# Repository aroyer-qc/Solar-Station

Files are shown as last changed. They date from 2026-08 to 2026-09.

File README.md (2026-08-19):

# SolarStation

ESP32-based solar station firmware for two-axis panel positioning, output scheduling, diagnostics, and network control. The firmware is designed for the Solar Station control PCB; its third stepper channel is currently unused by this project.

## Current Status

The firmware is in an active integration phase.

Implemented and working in firmware:

- FastAccelStepper integration with the PCB's 3 available stepper channels.
- Axis control on real steppers:
	- Azimuth controller uses Stepper1.
	- Elevation controller uses Stepper2.
	- Stepper3 is currently unused and available for future or other control applications.
- Configurable axis parameters (persisted):
	- Min/max angle limits.
	- Steps-per-degree ratio.
	- Step speed and acceleration.
- Portal dashboard + configuration UI (`/` and `/portal`) with sections for:
	- Solar tracking settings.
	- Axis settings.
	- Wi-Fi and NTP.
	- Output manual/auto control and schedules.
	- Hardware diagnostics (limit switches, driver DIAG, currents, sunrise/sunset).
- Output scheduler (3 outputs) with:
	- Fixed time or sunrise/sunset windows.
	- Duty cycle control.
	- AUTO/MANUAL mode per output.
- Wi-Fi behavior:
	- STA when configured.
	- AP fallback/setup mode when STA is not configured or fails.
- Sunset return preposition behavior:
	- Always active.
	- Executes once per target day.
	- Uses a fixed delay after local sunset before prepositioning to next sunrise target.
- Diagnostics override workflow:
	- Dedicated page (`/diag` and `/portal/diag`) to force azimuth/elevation for testing.
	- Canceling test mode returns panel to current calculated solar position.

## Testing Without Optional Hardware

The firmware includes compile-time switches for testing on an ESP32 without all of the connected hardware. In `Solar-Station.ino`, set any unavailable hardware feature to `0` before compiling:

```cpp
#define USE_BH1750_SENSOR 0  // Disable the BH1750 light sensor
#define USE_IO_EXPANDER   0  // Disable the PCA9538 I2C I/O expander
#define USE_M95P32        0  // Disable the M95P32 external SPI EEPROM
```

Available hardware switches:

- `USE_BH1750_SENSOR`: BH1750 light sensor support; default is `1`.
- `USE_IO_EXPANDER`: PCA9538 I2C I/O expander support; default is `1`.
- `USE_M95P32`: M95P32 external SPI EEPROM support; default is `1`.

Disable only the hardware that is not connected. With a feature disabled, its driver is excluded from the build and the related initialization and access code is skipped. The ESP32, firmware logic, web interface, and other enabled features can then be tested independently.

## Control PCB

The firmware is designed for the ESP32-based Solar Station control PCB shown below. The PCB can also be reused for other automation and control projects because it provides:

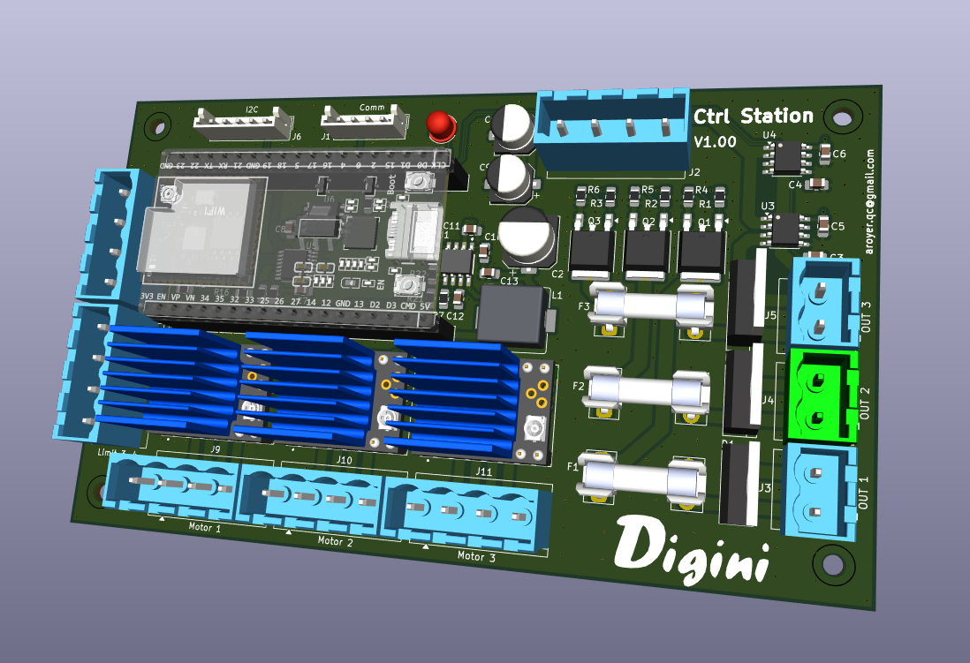
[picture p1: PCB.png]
Solar Station control PCB


- Three stepper motor controller channels; this project uses two for azimuth and elevation, while the third is currently unused.
- Inputs for switches such as limit switches and other digital status signals.
- Three MOSFET-controlled outputs that use the connected 12 V to 36 V power supply.
- One I2C port.
- One communication port.
- 3.3 V logic levels for the I2C and communication ports.

Check the electrical requirements of each connected motor, switch, and load before use. The MOSFET outputs switch the board's power-supply voltage, while the I2C and communication interfaces use 3.3 V logic.

## Hardware Notes (Current Wiring Assumptions)

- MCU: ESP32.
- Stepper drivers: TMC2209 (3 channels; two used by this project, one available).
- I/O expander: PCA9538 (I2C) for shared microstep pins, status LED, and limit switch inputs.
- External SPI EEPROM module support included (`M95PxxModule`).

## Main Runtime Modules

- `Solar-Station.ino`: orchestration, hardware init, scheduler, diagnostics helpers, sunset return, test override state.
- `ConfigModule.h` / `ConfigModule.ino`: persisted configuration storage and defaults.
- `AzimuthController.*`: azimuth axis control on FastAccelStepper.
- `ElevationController.*`: elevation axis control on FastAccelStepper.
- `WebServerModule.*`: synchronous web server routes and HTML placeholder binding.
- `WifiModule.*`: STA/AP behavior and reconnect strategy.
- `portal/index.html`: AP/setup portal page.
- `portal/diag.html`: diagnostics override page.
- `console/index.html`: full network console page.

Web UI deployment model:

- Local UI files are served from device filesystem (LittleFS/SPIFFS data partition).
- Use the `data` folder content and upload it with `tools/upload_spiffs.ps1` after firmware upload.
- Filesystem layout:
	- `data/portal/*` for AP/setup pages.
	- `data/console/*` for full network console pages.

## Web Endpoints (Current)

Main pages:

- `GET /` main dashboard/configuration page.
- `GET /portal` AP/setup portal page.
- `GET /diag` diagnostics test page.
- `GET /portal/diag` diagnostics test page.
- `GET /console` full network console page.
- `GET /diag/status` plain-text status snapshot for diagnostics page refresh.

Tracking diagnostics actions:

- `POST /setTrackingOverride` (form fields: `azimuth`, `elevation`).
- `POST /cancelTrackingOverride`.

Configuration actions (examples):

- `POST /saveSolarTrackingConfig`
- `POST /saveAzimuthConfig`
- `POST /saveElevationConfig`
- `POST /saveNTPConfig`
- `POST /saveWiFiConfig`
- `POST /saveScheduleConfig`

## Configuration Persistence

Configuration is stored with ESP32 Preferences.

- Main configuration uses a raw blob (`ConfigData_t`).
- Output AUTO/MANUAL flags are stored in separate keys (`out_auto_0..2`).

Important:

- Any structural change to `ConfigData_t` size causes existing blob data to be considered incompatible and defaults are restored on next boot.

## Build Portability (Another PC)

This project now includes the async network libraries in the project `libraries` folder, so the same code and patches follow the project:

- `libraries/ESPAsyncWebServer` (v3.1.0, with local compatibility patches)
- `libraries/AsyncTCP` (v1.1.4)
- `libraries/ESPAsyncTCP`

To build on another computer:

1. Install Arduino IDE 2.x.
2. Install `esp32` board platform in Boards Manager.
3. Open `Solar-Station.ino` from this project folder (do not copy only the `.ino` file).
4. Compile directly; do not install another conflicting `ESPAsyncWebServer` manually unless you intentionally want to replace the bundled one.

Recommended:

- If you already have other async web libraries globally installed in your Arduino libraries folder, keep versions aligned with this project to avoid API/link mismatches.

## Known Limitations / Work In Progress

- Legacy configuration compatibility paths and placeholder-based HTML binding remain in the codebase.
- Arduino IntelliSense can report false compile errors in editor context even when firmware logic is valid.
- Full production solar tracking loop policy (beyond targeted move and preposition behavior) may still need refinement for final deployment scenarios.

## Quick Validation Checklist

- Open `/` and verify dashboard values update.
- Confirm Wi-Fi mode (STA or AP fallback) is shown correctly.
- In configuration tabs, set axis limits/ratio/speed/acceleration and save.
- Use `/diag`:
	- Apply manual override.
	- Cancel test and verify return to current calculated position.
- Verify sunset return preposition occurs after sunset + fixed delay.

## License

This project is released under the [MIT License](https://opensource.org/license/mit/).

Project files contain their own headers where applicable.

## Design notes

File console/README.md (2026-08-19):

# SolarStation Console (ESP32-hosted)

This console UI is hosted directly by the ESP32 from filesystem storage.

Routes served by firmware:

- `/console`
- `/console/index.html`
- `/console/styles.css`
- `/console/app.js`

Deployment:

1. Keep source files in this folder for editing.
2. Copy or mirror files into `data/console`.
3. Upload SPIFFS with `tools/upload_spiffs.ps1`.

Notes:

- The console consumes the same device API endpoints as local pages.
- In AP mode, the default base URL is usually `http://192.168.4.1`.

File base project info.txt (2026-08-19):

https://www.youtube.com/watch?v=VaNVrE7-AO8

voir 9:30 pour savoir ou mettre arduino esp32fs-plugin
voir 21:00 pour savoir comment prendre une chart.js et la copier dans notre propre code

should see this : https://github.com/jblance/mpp-solar/tree/master
and this: https://github.com/cordelster/mppsolar_dashboards

https://github.com/HDwayne/SolarTracker

MC Series Register Map Overview
The MC Series (e.g., MC2420N10, MC2430N10, MC2440N10, MC2450N10) supports Modbus RTU communication via RS485.

 Here's a summary of key registers based on the official User manuals:
 Configuration Registers
 Register | Description              | Values / Range                         | 
 n01      | Battery Type             | 0: Sealed, 1: Gel, 2: Flooded, 3: User | 
 n02      | Equalization Voltage     | 12V: 14.8V, 24V: 29.6V                 | 
 n03      | Boost Voltage            | 12V: 14.4V, 24V: 28.8V                 | 
 n04      | Float Voltage            | 12V: 13.8V, 24V: 27.6V                 | 
 n05      | Boost Duration           | 10–120 min                             | 
 n06      | Equalization Duration    | 10–120 min                             | 
 n07      | Temperature Compensation | -3 to 0 mV/°C/cell                     | 
 n08      | System Voltage           | 0: Auto, 1: 12V, 2: 24V                | 
 n09      | Max Charging Current     | 10A–50A depending on model             | 

Monitoring Registers
 Register | Description            | 
 n30      | Battery Voltage        | 
 n31      | PV Input Voltage       | 
 n32      | Charging Current       | 
 n33      | Load Current           | 
 n34      | Controller Temperature | 
 n35      | Battery Temperature    | 
 n36      | Charging Power         | 
 n37      | Load Power             | 
These registers allow you to monitor real-time performance and adjust charging behavior.

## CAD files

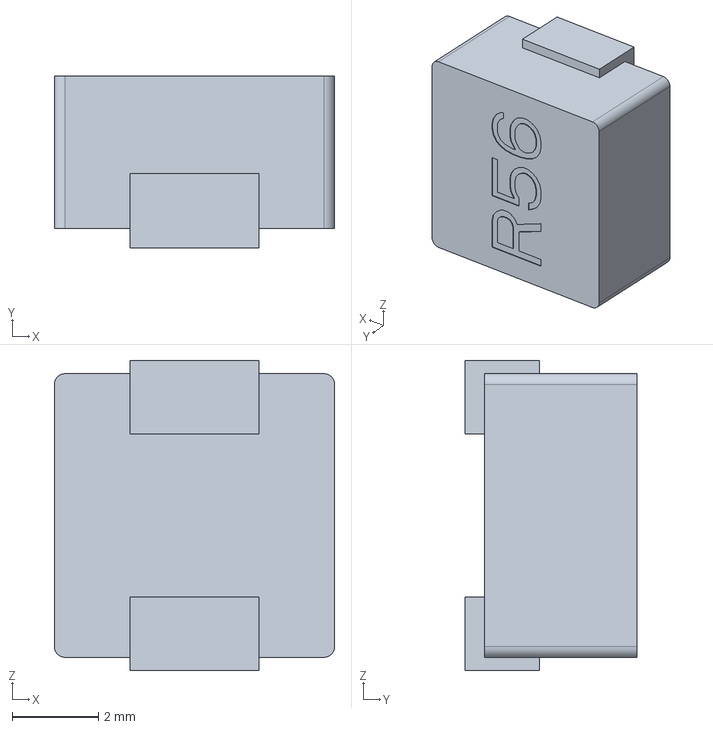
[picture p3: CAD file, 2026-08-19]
Ressource/ControlBox/srp6540-4r7m.stp
6.50 x 3.99 x 7.19 mm

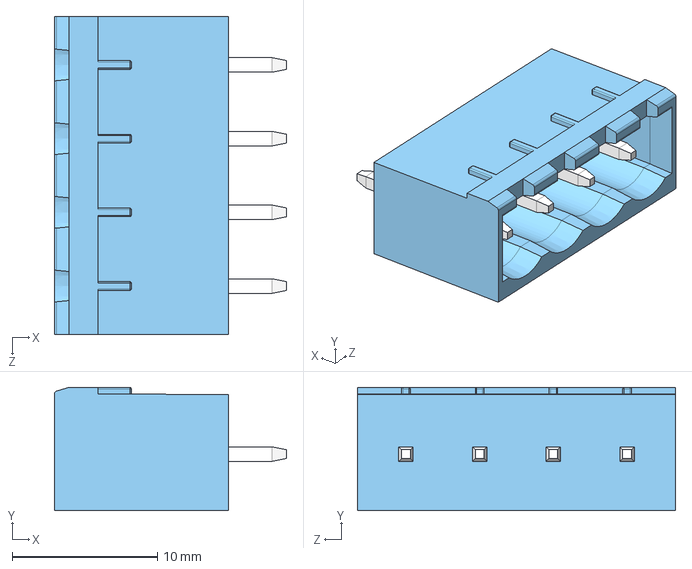
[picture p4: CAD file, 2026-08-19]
Ressource/ControlBox/TerminalBlock 4P.STEP
16.0 x 8.50 x 21.9 mm

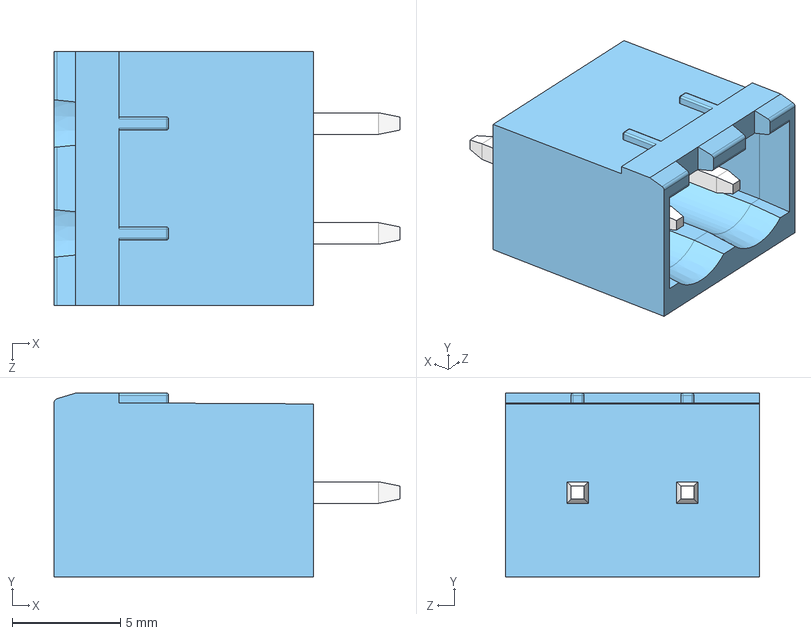
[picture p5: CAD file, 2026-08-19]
Ressource/ControlBox/TerminalBlock 2P.STEP
16.0 x 8.50 x 11.8 mm

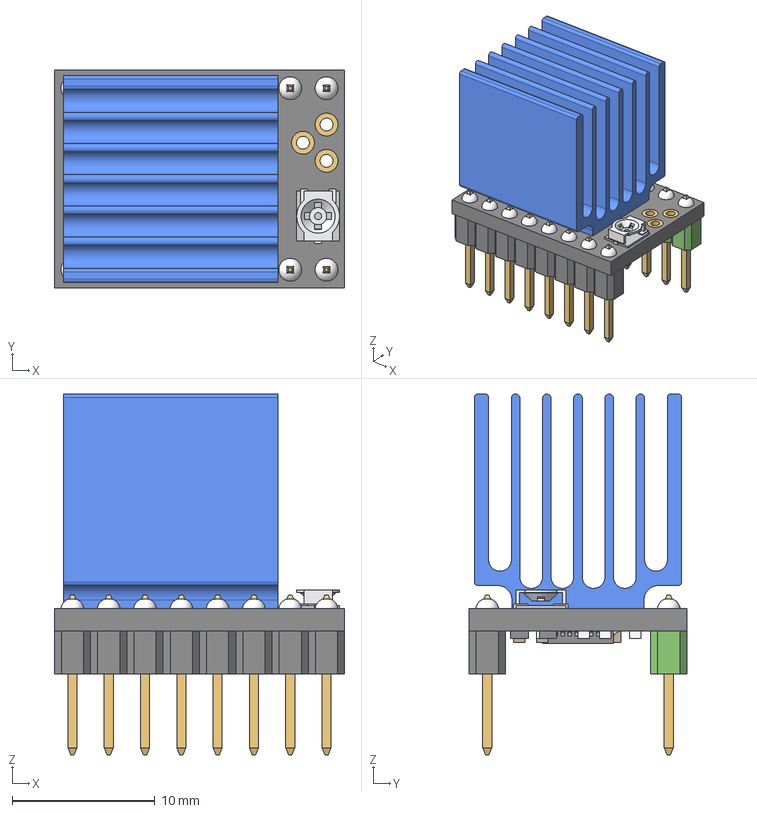
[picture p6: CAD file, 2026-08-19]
Ressource/ControlBox/TMC2209.step
20.3 x 15.2 x 25.3 mm
Body001 (Mirror #1)
Body001 (Mirror #1)001
Body001 (Mirror #1)002
Body001 (Mirror #1)003
Body001 (Mirror #1)004
Body001 (Mirror #1)005
Body001 (Mirror #1)006
Body001 (Mirror #1)007
Body001 (Mirror #1)008
Body001 (Mirror #1)009
Body001 (Mirror #1)010
Body001 (Mirror #1)011
Body001 (Mirror #1)012
Body001 (Mirror #1)013

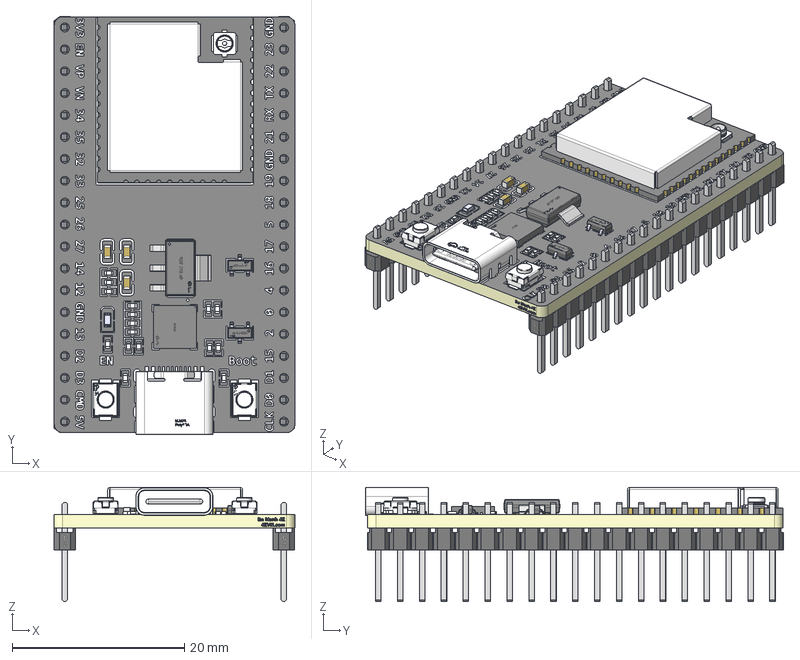
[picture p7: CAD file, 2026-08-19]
Ressource/ControlBox/ESP32-DEVKITC-32U.STEP
27.9 x 48.5 x 13.2 mm
Board~QTmk
TopSilkscreen~QTmk
BottomSilkscreen~QTmk
USB-C_SMD-TYPE-C-31-M-12~USB-C_SMD-TYPE-C-31-M-12~QTmk
C0603~C0603_L1.6-W0.8-H0.8~QTmk x 3
R0402~R0402_L1.0-W0.5-H0.4~QTmk x 16
SOT-223-3_L6.5-W3.4-P2.30-LS7.0-BR~SOT-223-4P_L6.5-W3.5-H1.6-LS7.0-P2. 30~QTmk
SW-SMD_L3.9-W3.0-P4.45~SW-SMD_L3.9-W2.9-H2.0-LS4.8~QTmk x 2
LED0603-RD_RED~LED0603-RD_RED~QTmk
HDR-TH_19P-P2.54-V-M~HDR-TH_19P-P2.54-M-LI-1X19P~QTmk x 2
SOT-23-3_L2.9-W1.3-P1.90-LS2.4-BR~SOT-23-3P_L2.9-W1.3-H1.0-LS2.4-P0.9 5~QTmk x 2
QFN-28_L5.0-W5.0-P0.50-TL-EP3.3~QFN-28_L5.0-W5.0-H0.9-P0.50~QTmk
ESP32_5x5_20210301.STEP^ESP32_5x5_20210301.STEP_Submodel-QFN48EB_0P35 _5_part_DesignRootModel_ESP32-WROOM-32UE(2)_ESP32-WROOM-32UE.STEP
DFN1006.STEP^DFN1006.STEP_Submodel-SOD882_part_DesignRootModel_ESP32- WROOM-32UE(2)_ESP32-WROOM-32UE.STEP
XTAL3225_20210301.STEP^XTAL3225_20210301.STEP_Submodel-XTAL3225_part_ DesignRootModel_ESP32-WROOM-32UE(2)_ESP32-WROOM-32UE.STEP
C0402_20210301.STEP^C0402_20210301.STEP_Submodel-C0402_part_DesignRoo tModel_ESP32-WROOM-32UE(2)_ESP32-WROOM-32UE.STEP
SOIC8_208_20210301.STEP^SOIC8_208_20210301.STEP_Submodel-SOP8_1P27_6P 6_part_DesignRootModel_ESP32-WROOM-32UE(2)_ESP32-WROOM-32UE.STEP
L0201_20210301.STEP^L0201_20210301.STEP_Submodel-L0201_part_DesignRoo tModel_ESP32-WROOM-32UE(2)_ESP32-WROOM-32UE.STEP x 2
R0201_20210301.STEP^R0201_20210301.STEP_Submodel-R0201_part_DesignRoo tModel_ESP32-WROOM-32UE(2)_ESP32-WROOM-32UE.STEP x 3
C0201_20210301.STEP^C0201_20210301.STEP_Submodel-C0201_part_DesignRoo tModel_ESP32-WROOM-32UE(2)_ESP32-WROOM-32UE.STEP x 15
uid__1081685072^DesignRootModel_ESP32-WROOM-32UE(2)_ESP32-WROOM-32UE. STEP
pad.STEP x 38
ESP32-WROOM-32U_Shieldingcase_20210312.STEP
32E_thermal_pad.STEP
I-IPEX

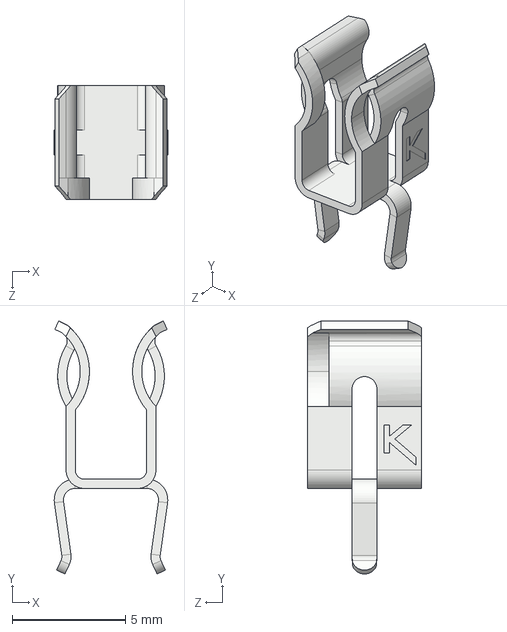
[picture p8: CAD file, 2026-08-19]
Ressource/ControlBox/FuseHolderClip.STEP
5.00 x 11.1 x 5.00 mm

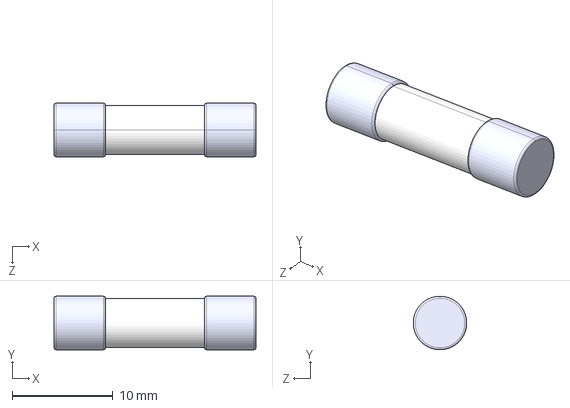
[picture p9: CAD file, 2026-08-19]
Ressource/ControlBox/fuse.STEP
20.0 x 5.30 x 5.30 mm

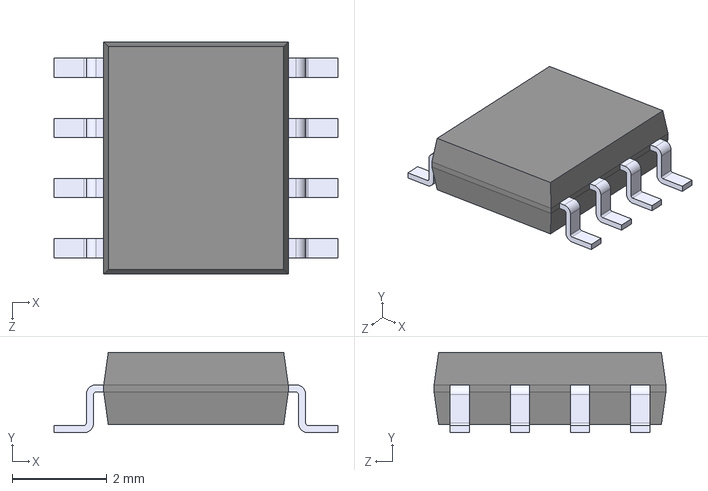
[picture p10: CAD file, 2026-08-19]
Ressource/ControlBox/AP64100SP-13.STEP
6.00 x 1.70 x 4.90 mm

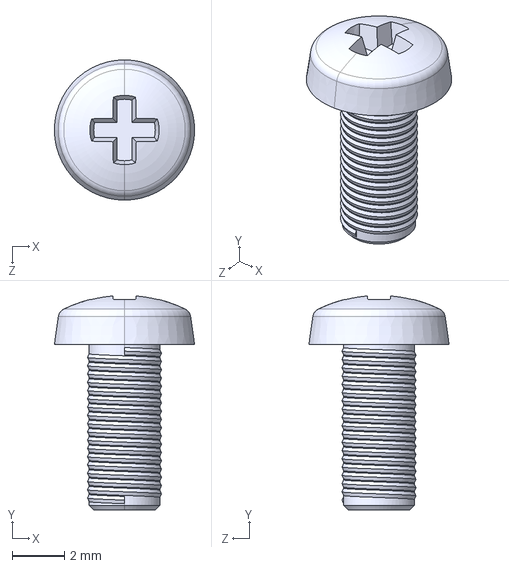
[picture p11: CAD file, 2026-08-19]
Ressource/ControlBox/screw M2x20.STEP
5.38 x 8.21 x 5.38 mm

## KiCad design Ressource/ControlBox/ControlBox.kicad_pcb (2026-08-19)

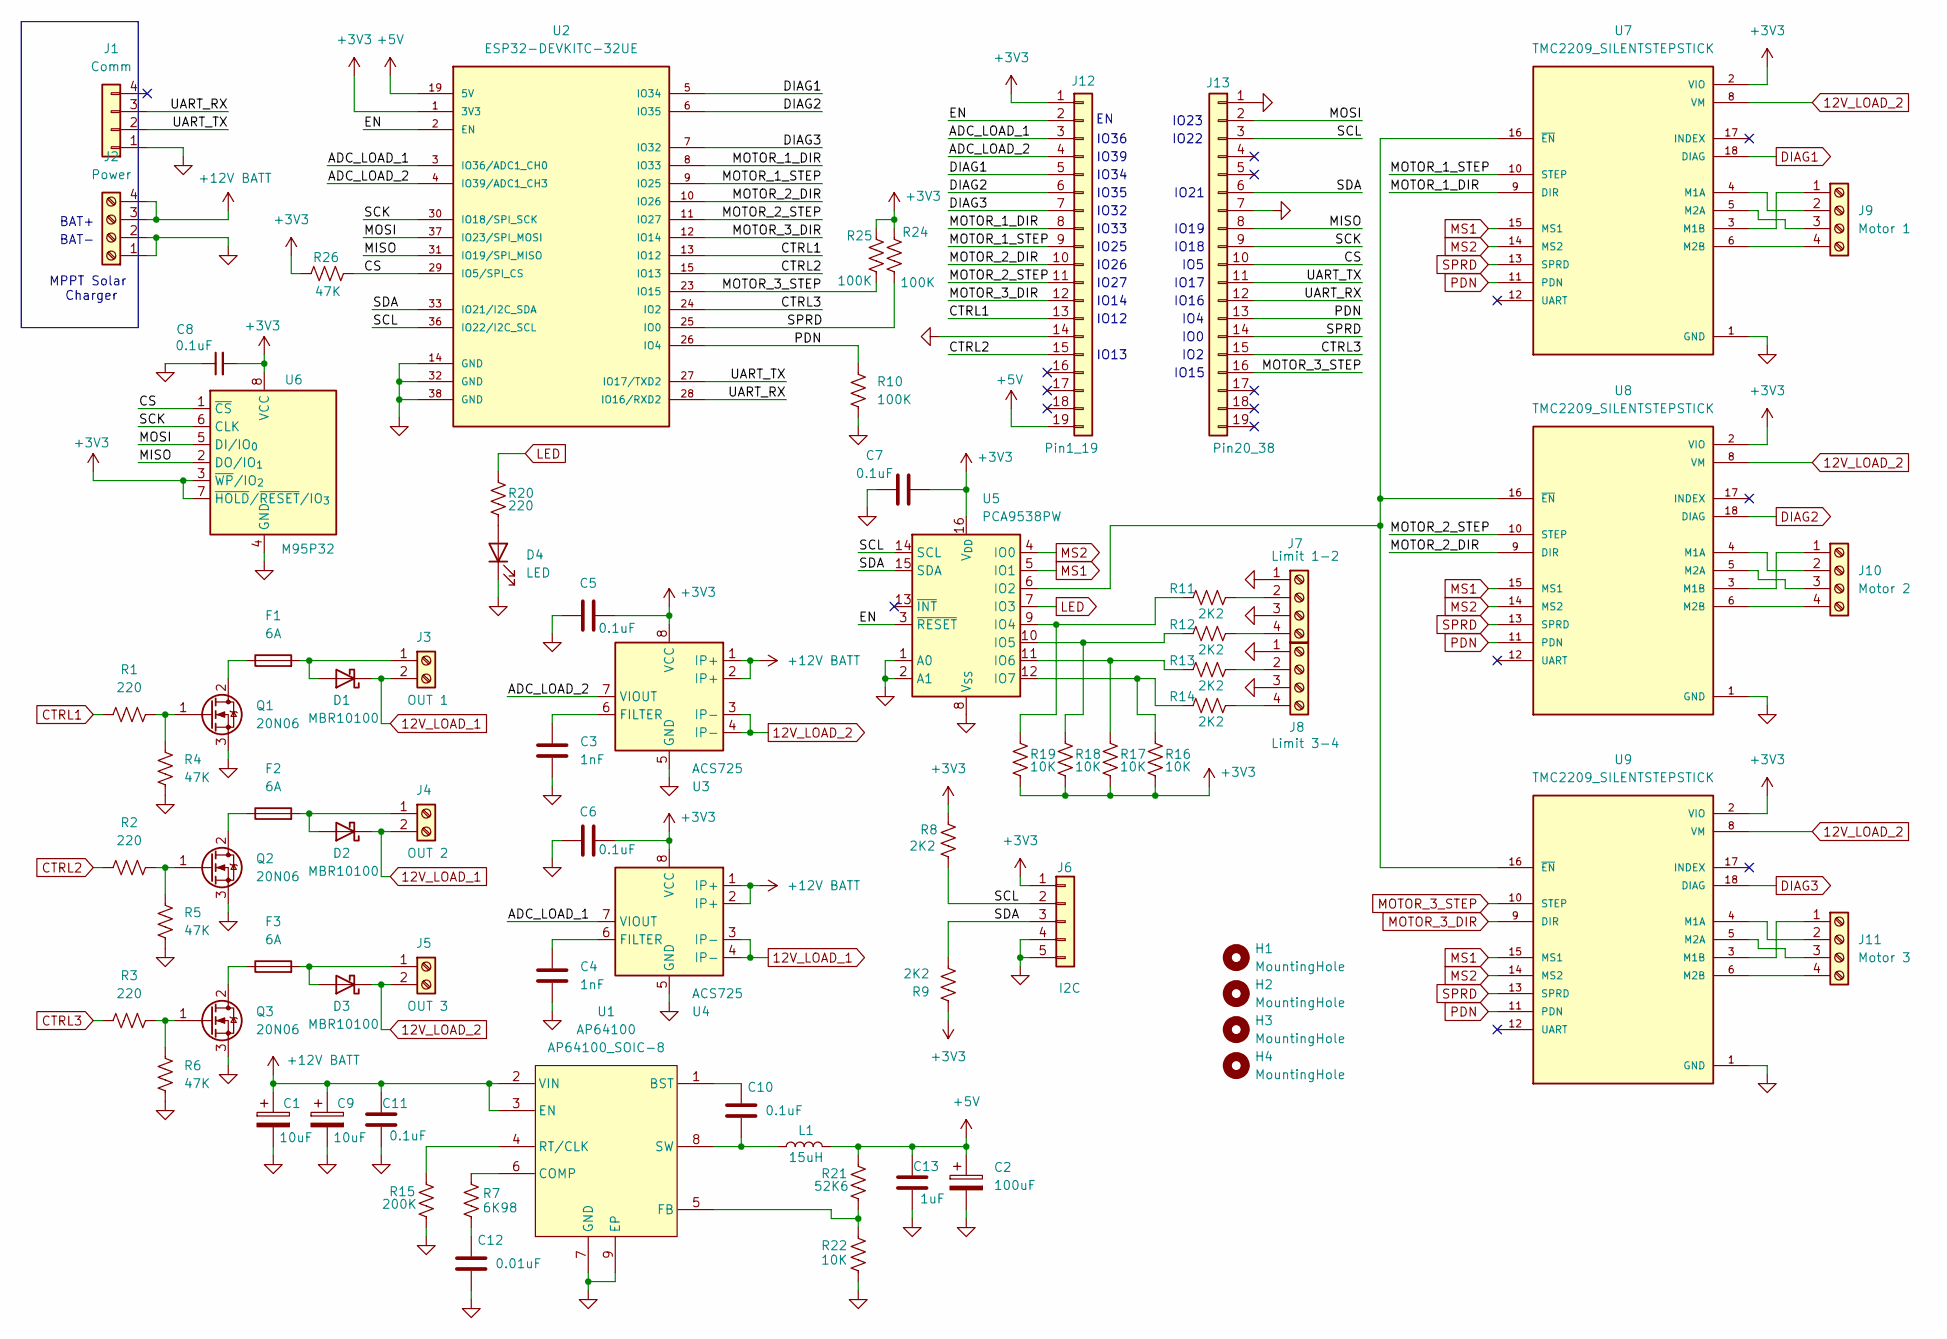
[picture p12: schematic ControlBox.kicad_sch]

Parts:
C1, C9: 10uF; CP_Elec_6.3x5.4
C2: 100uF; CP_Elec_8x6.7
C3, C4: 1nF; C_0805_2012Metric_Pad1.18x1.45mm_HandSolder
C5, C6, C7, C8, C10, C11: 0.1uF; C_0805_2012Metric_Pad1.18x1.45mm_HandSolder
C12: 0.01uF; C_0805_2012Metric_Pad1.18x1.45mm_HandSolder
C13: 1uF; C_0805_2012Metric_Pad1.18x1.45mm_HandSolder
D1, D2, D3: MBR10100; TO-220-2_Vertical
D4: LED; LED_D4.0mm
F1, F2, F3: 6A; Fuseholder_Clip-4x15mm_Generic_Horizontal
H1, H2, H3, H4: MountingHole; MountingHole_2.7mm_M2.5
J1: Comm; JST_EH_B4B-EH-A_1x04_P2.50mm_Vertical
J2: Power; TerminalBlock_CUI_TB007-508-04_1x04_P5.08mm_Horizontal
J3: OUT 1; TerminalBlock_CUI_TB007-508-02_1x02_P5.08mm_Horizontal
J4: OUT 2; TerminalBlock_CUI_TB007-508-02_1x02_P5.08mm_Horizontal
J5: OUT 3; TerminalBlock_CUI_TB007-508-02_1x02_P5.08mm_Horizontal
J6: I2C; JST_EH_B5B-EH-A_1x05_P2.50mm_Vertical
J7: Limit 1-2; TerminalBlock_CUI_TB007-508-04_1x04_P5.08mm_Horizontal
J8: Limit 3-4; TerminalBlock_CUI_TB007-508-04_1x04_P5.08mm_Horizontal
J9: Motor 1; TerminalBlock_CUI_TB007-508-04_1x04_P5.08mm_Horizontal
J10: Motor 2; TerminalBlock_CUI_TB007-508-04_1x04_P5.08mm_Horizontal
J11: Motor 3; TerminalBlock_CUI_TB007-508-04_1x04_P5.08mm_Horizontal
J12: Pin1_19; PinHeader_1x19_P2.54mm_Vertical
J13: Pin20_38; PinHeader_1x19_P2.54mm_Vertical
L1: 15uH; L_Bourns_SRP1038C_10.0x10.0mm
Q1, Q2, Q3: 20N06; TO-252-2
R1, R2, R3, R20: 220; R_0805_2012Metric_Pad1.20x1.40mm_HandSolder
R4, R5, R6, R26: 47K; R_0805_2012Metric_Pad1.20x1.40mm_HandSolder
R7: 6K98; R_0805_2012Metric_Pad1.20x1.40mm_HandSolder
R8, R9, R11, R12, R13, R14: 2K2; R_0805_2012Metric_Pad1.20x1.40mm_HandSolder
R10, R24, R25: 100K; R_0805_2012Metric_Pad1.20x1.40mm_HandSolder
R15: 200K; R_0805_2012Metric_Pad1.20x1.40mm_HandSolder
R16, R17, R18, R19, R22: 10K; R_0805_2012Metric_Pad1.20x1.40mm_HandSolder
R21: 52K6; R_0805_2012Metric_Pad1.20x1.40mm_HandSolder
U1: AP64100; AP64100_SOIC-8
U2: ESP32-DEVKITC-32UE; PARTREV V4
U3, U4: ACS725; SOIC-8_3.9x4.9mm_P1.27mm
U5: PCA9538PW; TSSOP-16_4.4x5mm_P0.65mm
U6: M95P32; SOIC-8_5.3x5.3mm_P1.27mm
U7, U8, U9: TMC2209_SILENTSTEPSTICK; MOD_TMC2209; PARTREV 1.20

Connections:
12V_LOAD_1: D1.1 (K), D2.1 (K), J3.2, J4.2, U4.3 (IP-), U4.4 (IP-)
12V_LOAD_2: D3.1 (K), J5.2, U3.3 (IP-), U3.4 (IP-), U7.8 (VM), U8.8 (VM), U9.8 (VM)
+3V3: C5.2, C6.2, C7.2, C8.2, J6.1, J12.1, R8.1, R9.1, R16.2, R17.2, R18.2, R19.2, R24.1, R25.1, R26.1, U2.1 (3V3), U3.8 (VCC), U4.8 (VCC), U5.16 (V_{DD}), U6.3 (~WP/IO_{2}), U6.7 (~HOLD/~RESET/IO_{3}), U6.8 (VCC), U7.2 (VIO), U8.2 (VIO), U9.2 (VIO)
+5V: C2.1, C13.1, J12.19, L1.2, R21.1, U2.19 (5V)
+12V BATT: C1.1, C9.1, C11.1, J2.3, J2.4, U1.2 (VIN), U1.3 (EN), U3.1 (IP+), U3.2 (IP+), U4.1 (IP+), U4.2 (IP+)
/ADC_LOAD_1: J12.3, U2.3 (IO36/ADC1_CH0), U4.7 (VIOUT)
/ADC_LOAD_2: J12.4, U2.4 (IO39/ADC1_CH3), U3.7 (VIOUT)
/CS: J13.10, R26.2, U2.29 (IO5/SPI_CS), U6.1 (~CS)
/EN: J12.2, U2.2 (EN), U5.3 (~RESET)
/MISO: J13.8, U2.31 (IO19/SPI_MISO), U6.2 (DO/IO_{1})
/MOSI: J13.2, U2.37 (IO23/SPI_MOSI), U6.5 (DI/IO_{0})
/MOTOR_1_DIR: J12.8, U2.8 (IO33), U7.9 (DIR)
/MOTOR_1_STEP: J12.9, U2.9 (IO25), U7.10 (STEP)
/MOTOR_2_DIR: J12.10, U2.10 (IO26), U8.9 (DIR)
/MOTOR_2_STEP: J12.11, U2.11 (IO27), U8.10 (STEP)
/SCK: J13.9, U2.30 (IO18/SPI_SCK), U6.6 (CLK)
/SCL: J6.2, J13.3, R8.2, U2.36 (IO22/I2C_SCL), U5.14 (SCL)
/SDA: J6.3, J13.6, R9.2, U2.33 (IO21/I2C_SDA), U5.15 (SDA)
/UART_RX: J1.3, J13.12, U2.28 (IO16/RXD2)
/UART_TX: J1.2, J13.11, U2.27 (IO17/TXD2)
CTRL1: J12.13, R1.1, U2.13 (IO12)
CTRL2: J12.15, R2.1, U2.15 (IO13)
CTRL3: J13.15, R3.1, U2.24 (IO2)
DIAG1: J12.5, U2.5 (IO34), U7.18 (DIAG)
DIAG2: J12.6, U2.6 (IO35), U8.18 (DIAG)
DIAG3: J12.7, U2.7 (IO32), U9.18 (DIAG)
GND: C1.2, C2.2, C3.2, C4.2, C5.1, C6.1, C7.1, C8.1, C9.2, C11.2, C12.2, C13.2, D4.1 (K), J1.1, J2.1, J2.2, J6.4, J6.5, J7.1, J7.3, J8.1, J8.3, J12.14, J13.1, J13.7, Q1.3 (S), Q2.3 (S), Q3.3 (S), R4.2, R5.2, R6.2, R10.2, R15.2, R22.2, U1.7 (GND), U1.9 (EP), U2.14 (GND), U2.32 (GND), U2.38 (GND), U3.5 (GND), U4.5 (GND), U5.1 (A0), U5.2 (A1), U5.8 (V_{SS}), U6.4 (GND), U7.1 (GND), U7.7 (GND), U8.1 (GND), U8.7 (GND), U9.1 (GND), U9.7 (GND)
LED: R20.1, U5.7 (IO3)
MOTOR_3_DIR: J12.12, U2.12 (IO14), U9.9 (DIR)
MOTOR_3_STEP: J13.16, R25.2, U2.23 (IO15), U9.10 (STEP)
MS1: U5.5 (IO1), U7.15 (MS1), U8.15 (MS1), U9.15 (MS1)
MS2: U5.4 (IO0), U7.14 (MS2), U8.14 (MS2), U9.14 (MS2)
unnamed: C12.1, R7.2
unnamed: D1.2 (A), F1.2, J3.1
unnamed: D2.2 (A), F2.2, J4.1
unnamed: D3.2 (A), F3.2, J5.1
unnamed: D4.2 (A), R20.2
unnamed: J7.2, R11.2
unnamed: J7.4, R12.2
unnamed: J8.2, R13.2
unnamed: J8.4, R14.2
unnamed: J9.1, U7.3 (M1B)
unnamed: J9.2, U7.4 (M1A)
unnamed: J9.3, U7.5 (M2A)
unnamed: J9.4, U7.6 (M2B)
unnamed: J10.1, U8.3 (M1B)
unnamed: J10.2, U8.4 (M1A)
unnamed: J10.3, U8.5 (M2A)
unnamed: J10.4, U8.6 (M2B)
unnamed: J11.1, U9.3 (M1B)
unnamed: J11.2, U9.4 (M1A)
unnamed: J11.3, U9.5 (M2A)
unnamed: J11.4, U9.6 (M2B)
unnamed: F1.1, Q1.2 (D)
unnamed: Q1.1 (G), R1.2, R4.1
unnamed: F2.1, Q2.2 (D)
unnamed: Q2.1 (G), R2.2, R5.1
unnamed: F3.1, Q3.2 (D)
unnamed: Q3.1 (G), R3.2, R6.1
unnamed: C10.1, U1.1 (BST)
unnamed: R7.1, U1.6 (COMP)
unnamed: R21.2, R22.1, U1.5 (FB)
unnamed: R15.1, U1.4 (RT/CLK)
unnamed: C10.2, L1.1, U1.8 (SW)
unnamed: C3.1, U3.6 (FILTER)
unnamed: C4.1, U4.6 (FILTER)
unnamed: U5.6 (IO2), U7.16 (~EN), U8.16 (~EN), U9.16 (~EN)
unnamed: R11.1, R19.1, U5.9 (IO4)
unnamed: R12.1, R18.1, U5.10 (IO5)
unnamed: R13.1, R17.1, U5.11 (IO6)
unnamed: R14.1, R16.1, U5.12 (IO7)
PDN: J13.13, R10.1, U2.26 (IO4), U7.11 (PDN), U8.11 (PDN), U9.11 (PDN)
SPRD: J13.14, R24.2, U2.25 (IO0), U7.13 (SPRD), U8.13 (SPRD), U9.13 (SPRD)

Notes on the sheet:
IO32
IO27
IO17
MPPT Solar Charger
IO13
BAT-
IO36
IO21
IO18
IO14
IO25
IO26
IO0
IO34
IO19
IO35
IO15
IO2
IO4
IO16
IO33
IO22
IO5
IO12
IO23
IO39
BAT+

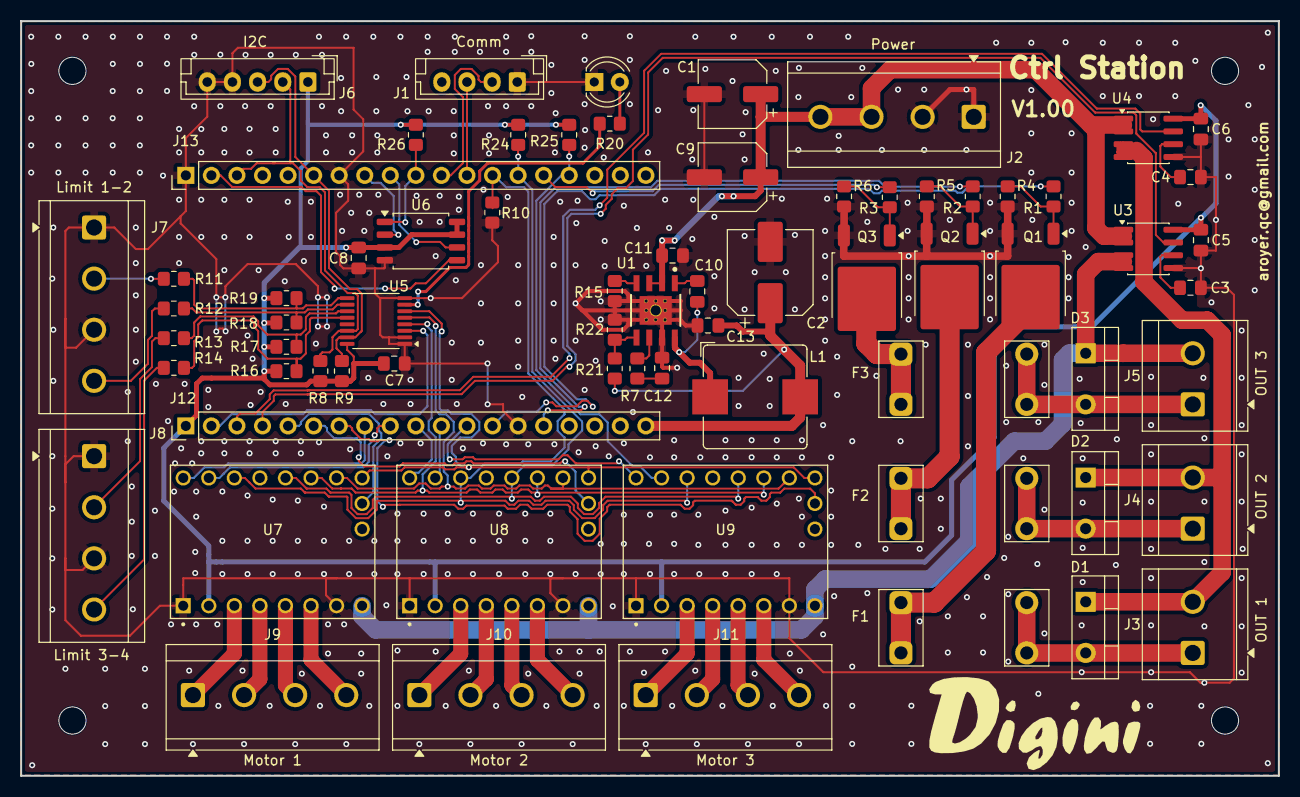
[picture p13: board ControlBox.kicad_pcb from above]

Board: 2 copper layers, 125.0 x 75.0 mm, 74 parts (0 on the bottom side), 73 nets.

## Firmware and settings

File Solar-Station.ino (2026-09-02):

//-------------------------------------------------------------------------------------------------
//
//  File : Solar-Station.ino
//
//-------------------------------------------------------------------------------------------------
//
// Copyright(c) 2025 Alain Royer.
// Email: aroyer.qc@gmail.com
//
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
//-------------------------------------------------------------------------------------------------
//
//    Solar Station
//
//        - Tracking panel.
//            * control motor.
//        
//        - Monitor panel voltage and current.
//        - Monitor battery voltage and current flow in or out.
//        - monitor load current.
//        - Control IO according to schedule and or power availability
//        - more to add...
//
//
// Filesystem upload procedure (required to serve local web pages from /data):
// 1) Build and upload firmware from Arduino IDE as usual.
// 2) Open PowerShell in the project root folder.
// 3) Run the helper script with your serial port and partition scheme.
//
// Example commands:
//   .\tools\upload_spiffs.ps1 -Port COMx -Partition default
//   .\tools\upload_spiffs.ps1 -Port COMx -Partition no_ota
//   .\tools\upload_spiffs.ps1 -Port COMx -Partition huge_app
//   .\tools\upload_spiffs.ps1 -Port COMx -Partition min_spiffs
//
// Notes:
// - Use the same partition scheme selected in Arduino IDE (Tools > Partition Scheme).
// - The script packs files from /data into a SPIFFS image and writes it to flash.
// - If pages are blank, upload firmware then rerun this script and reboot the ESP32.
//
//
//-------------------------------------------------------------------------------------------------

//-------------------------------------------------------------------------------------------------
// Include file(s)
//-------------------------------------------------------------------------------------------------

#include <Wire.h>

// #define USE_DEBUG_APP

#ifndef USE_BH1750_SENSOR
#define USE_BH1750_SENSOR            1
#endif

#ifndef USE_IO_EXPANDER
#define USE_IO_EXPANDER              1
#endif

#ifndef USE_M95P32
#define USE_M95P32                   1
#endif

#if USE_BH1750_SENSOR
#include <BH1750.h>
#endif
#include "SolarFixed.h"
#include <math.h>
#include "ConfigModule.h"
#include "WiFiModule.h"
#include "WebServerModule.h"
#include "TelemetryModule.h"
#include "SchedulerModule.h"
#include "TrackingModule.h"
#include "FastAccelStepper.h"
#include "AzimuthController.h"
#include "ElevationController.h"
#include "SensorLoggerModule.h"
#include <sys/time.h>

#if USE_M95P32
#include "M95PxxModule.h"
#endif

//-------------------------------------------------------------------------------------------------
// Define(s)
//-------------------------------------------------------------------------------------------------

// Miscellaneous Default

#define DEFAULT_SERIAL_BAUD_RATE        115200

//-------------------------------------------------------------------------------------------------
// Default positions

//-------------------------------------------------------------------------------------------------
// IO definitions

// UART2 (configure pins as needed)
// ESP32 module pins: 27 -> GPIO16, 28 -> GPIO17
#define UART2_TX_PIN                    17
#define UART2_RX_PIN                    16
#define UART2_BAUDRATE                  9600
#define MPPT_MODBUS_ADDRESS             0xFF
#define MPPT_MODBUS_FUNC_READ_HOLDING   0x03

// Read Battery SOC (Value * 1 - Ex: 0x00 0x37 = 55%)
// CMD:	0x100  Bytes Read 2
// Read Battery voltage (Value * 0.1 - Ex: 0x00 0x7A = 12.2V)
// CMD:	0x101  Bytes Read 2
// Read Charging Current to Battery (Value * 0.01 - Ex: 0x01 0x0A = 2.66A)
// CMD:	0x102  Bytes Read 2
// Read Panel voltage (Value * 0.1 - Ex: 0x00 0xC8 = 20.0V)
// CMD:	0x107  Bytes Read 2
// Read Panel current to controller (Value * 0.01 - Ex: 0x01 0x0A = 2.66A)
// CMD:	0x108  Bytes Read 2
// Read Panel Charging power (Value * 1 - Ex: 0x00 0x35 = 55W)
// CMD:	0x109  Bytes Read 2
#define MPPT_REG_BATTERY_SOC            0x0100
#define MPPT_REG_BATTERY_VOLTAGE        0x0101
#define MPPT_REG_CHARGE_CURRENT         0x0102
#define MPPT_REG_PANEL_VOLTAGE          0x0107
#define MPPT_REG_PANEL_CURRENT          0x0108
#define MPPT_REG_PANEL_CHARGING_POWER   0x0109
// UART2 Serial port

// PCA9538PW (MS1/MS2 via IO expander on I2C)
#define PCA9538_I2C_ADDRESS             0x70
#define PCA9538_REG_INPUT               0x00
#define PCA9538_REG_OUTPUT              0x01
#define PCA9538_REG_POLARITY            0x02
#define PCA9538_REG_CONFIG              0x03

// 3x TMC2209 stepper wiring
#define STEPPER1_DIR_PIN                33
#define STEPPER1_STEP_PIN               25
#define STEPPER2_DIR_PIN                26
#define STEPPER2_STEP_PIN               27
#define STEPPER3_DIR_PIN                14
#define STEPPER3_STEP_PIN               15

// Driver diagnostic inputs
#define STEPPER1_DIAG_PIN               34
#define STEPPER2_DIAG_PIN               35
#define STEPPER3_DIAG_PIN               32

// Adjust to LOW if your driver DIAG is active-low
#define STEPPER_DIAG_ACTIVE_STATE       HIGH

// Shared control lines for all 3 drivers
#define STEPPER_PDN_SHARED_PIN           4
#define STEPPER_SPRD_SHARED_PIN          0

// Defaults can be updated later from config/IO expander logic
#define STEPPER_PDN_DEFAULT_STATE        HIGH
#define STEPPER_SPRD_DEFAULT_STATE       LOW

// PCA9538 pin mapping for microstep control (shared in parallel for all 3 steppers)
// MS2 -> IO0, MS1 -> IO1
#define STEPPER_MS2_EXP_PIN              0
#define STEPPER_MS1_EXP_PIN              1
#define STEPPER_EN_EXP_PIN               2

// Shared TMC2209 EN line through PCA9538 IO2.
// Most TMC2209 modules use EN active-low.
#define STEPPER_EN_ACTIVE_STATE          LOW
#define STEPPER_EN_INACTIVE_STATE        HIGH

// PCA9538 status LED output
#define STATUS_LED_EXP_PIN               3
#define STATUS_LED_ON_STATE              LOW
#define STATUS_LED_OFF_STATE             HIGH
#define STATUS_LED_BLINK_INTERVAL_MS     500

// PCA9538 limit switches (wired to GND)
#define LIMIT_SWITCH1_EXP_PIN            4
#define LIMIT_SWITCH2_EXP_PIN            5
#define LIMIT_SWITCH3_EXP_PIN            6
#define LIMIT_SWITCH4_EXP_PIN            7
#define LIMIT_SWITCH_ACTIVE_STATE        LOW

// Default microstep profile on MS pins (can be changed from config later)
#define STEPPER_MS1_DEFAULT_STATE        LOW
#define STEPPER_MS2_DEFAULT_STATE        LOW

// ADC on ADC1
// ACS725 sensors:
// - Load 1 current on ADC1_CH0 (GPIO36)
// - Load 2 current on ADC1_CH3 (GPIO39)
#define ACS725_SENS_CUR_LOAD1_PIN        36
#define ACS725_SENS_CUR_LOAD2_PIN        39

// 3x MOSFET low-side outputs
#define MOSFET_OUTPUT1_PIN               12
#define MOSFET_OUTPUT2_PIN               13
#define MOSFET_OUTPUT3_PIN               2

// ESP32 LEDC PWM configuration for MOSFET outputs
#define MOSFET_PWM_FREQ_HZ               20000
#define MOSFET_PWM_RES_BITS              10

//-------------------------------------------------------------------------------------------------

// Per-sensor calibration:
// - SIGN: use +1.0f for normal polarity, -1.0f to invert current direction
// - OFFSET_A: residual current offset in amps when true current is 0 A

#define ADC_REF_VOLTAGE                  (float(3.3))                // ESP32 ADC reference/supply voltage
#define ESP32_ADC_RESOLUTION             4095                        // 12-bit ADC
#define ACS725_SAMPLES_PER_READ          8u
#define ACS725_LOAD1_SENSITIVITY_V_PER_A (float(0.132))              // ACS725 0-20A unidirectional sensitivity at 3.3V (about 132mV/A)
#define ACS725_LOAD2_SENSITIVITY_V_PER_A (float(0.132))              // ACS725 0-20A unidirectional sensitivity at 3.3V (about 132mV/A)
#define ACS725_LOAD1_ZERO_CURRENT_VOLTAGE (float(0.33))              // Unidirectional quiescent output near 10% of Vcc (adjust by calibration)
#define ACS725_LOAD2_ZERO_CURRENT_VOLTAGE (float(0.33))              // Unidirectional quiescent output near 10% of Vcc (adjust by calibration)

// Per-sensor calibration:
// - SIGN: use +1.0f for normal polarity, -1.0f to invert current direction
// - OFFSET_A: residual current offset in amps when true current is 0 A
#define ACS725_LOAD1_SIGN                (1.0f)
#define ACS725_LOAD2_SIGN                (1.0f)
#define ACS725_LOAD1_OFFSET_A            (0.0f)
#define ACS725_LOAD2_OFFSET_A            (0.0f)
#define ACS725_CLAMP_NEGATIVE_TO_ZERO    1
#define VAR_UNUSED(v)                    ((void)(v))

static constexpr uint32_t OUTPUT_SCHEDULE_UPDATE_MS = 1000u;
static constexpr uint32_t MORNING_RETURN_CHECK_MS = 15000u;
static constexpr uint16_t MORNING_RETURN_DELAY_AFTER_RED_MIN = 30u;
static constexpr uint32_t PANEL_ADJUSTMENT_INTERVAL_MS = 1000u;
static constexpr uint32_t SENSOR_REFRESH_MS = 2000u;
static constexpr uint32_t MPPT_POLL_INTERVAL_MS = 1000u;
static constexpr uint32_t MPPT_RESPONSE_TIMEOUT_MS = 200u;
static constexpr uint32_t SUNSET_RETURN_CHECK_MS = 15000u;
static constexpr uint16_t RETURN_DELAY_AFTER_SUNSET_MIN = 30u;
static constexpr uint32_t ADC_LOG_SAMPLE_INTERVAL_MS = 1000u;
static constexpr uint32_t ADC_LOG_AVG_WINDOW_MS = 2000u;
static constexpr uint32_t LUX_LOG_SAMPLE_INTERVAL_MS = SENSOR_REFRESH_MS;
static constexpr uint32_t LUX_LOG_AVG_WINDOW_MS = 2000u;
// MPPT values move slowly; a wide window keeps nine channels within the retention budget.
static constexpr uint32_t MPPT_LOG_SAMPLE_INTERVAL_MS = MPPT_POLL_INTERVAL_MS;
static constexpr uint32_t MPPT_LOG_AVG_WINDOW_MS = 30000u;
static constexpr uint8_t LOG_RETENTION_THRESHOLD_PERCENT = 80u;

//-------------------------------------------------------------------------------------------------
//  Typedef(s)
//-------------------------------------------------------------------------------------------------

enum State_e            // Common Controller Status Bits
{
    CHARGING                    = 0,            // Charging:                Controller is actively charging the battery.
    FLOAT_MODE                  = 1,            // Float Mode:              Battery is in float charging stage.
    BOOST_MODE                  = 2,            // Boost Mode:              Battery is in boost charging stage.
    EQULIZATION_MODE            = 3,            // Equalization Mode:       Equalization charging is active.
    OVERLOAD                    = 4,            // Overload:                Load current exceeds rated capacity (N/U).
    OVER_TEMPERATURE            = 5,            // Over Temperature         Controller temperature exceeds safe limit.
    BATTERY_OVER_VOLTAGE        = 6,            // Battery Over Voltage     Battery voltage too high.
    BATTERY_UNDER_VOLTAGE       = 7,            // Battery Under Voltage    Battery voltage too low.
    PANEL_OVER_VOLTAGE          = 8,            // PV Over Voltage          Solar panel
    PANEL_OVER_CURRENT          = 9,            // PV Over Current          Solar panel
    COMMUNICATION_ERROR         = 10,           // Communication Error      Modbus or RS485 communication fault.
    LOAD_ON                     = 11,           // Load On                  Load output is enabled (not supported).
    LOAD_OFF                    = 12,           // Load Off                 Load output is disabled (not supported).
};

//-------------------------------------------------------------------------------------------------
// Variable(s)
//-------------------------------------------------------------------------------------------------

//-------------------------------------------------------------------------------------------------
// IP with default value
#ifdef USE_WIFI
#endif

uint32_t                TickCounter;
#if USE_BH1750_SENSOR
BH1750                  LightMeter;
#endif


WifiModule              Wifi;
WebServerModule         WebServer;
AzimuthController       azimuthController;
ElevationController     elevationController;

#if USE_M95P32
M95PxxModule            Eeprom;
#endif
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
void loop() // Became Idle task
{
    static uint32_t lastScheduleUpdate = 0;
    static uint32_t lastSunsetReturnCheck = 0;
    static uint32_t lastPanelAdjustment = 0;
    static bool trackingInitialized = false;
    uint32_t now = millis();

    // Initialize tracking with calculated solar position on first valid time (after NTP sync or fallback).
    // This prevents unwanted motor movement at boot-up.
    if(!trackingInitialized && IsSystemTimeValid())
    {
        trackingInitialized = true;
        InitializeTrackingFromSolarPosition();
    }

    UpdateStatusLedHeartbeat();
    ProcessPendingMicrostepConfigApply();

    if(!TrackingTestOverrideActive)
    {
        if((now - lastPanelAdjustment) >= PANEL_ADJUSTMENT_INTERVAL_MS)
        {
            lastPanelAdjustment = now;
            MovePanelToCurrentCalculatedPosition();
        }
    }

    if((now - lastScheduleUpdate) >= OUTPUT_SCHEDULE_UPDATE_MS)
    {
        lastScheduleUpdate = now;
        ApplyOutputSchedules();
    }

    if((now - lastSunsetReturnCheck) >= SUNSET_RETURN_CHECK_MS)
    {
        lastSunsetReturnCheck = now;
        ApplySunsetReturnPreposition();
    }

    UpdateMpptTelemetry(now);
    UpdateLoadCurrentTelemetry(now);
    
    UpdateSensorDataLogging(now);

    Wifi.Loop();
    WebServer.Loop();

    if(WebServer.isRestartRequested())
    {
      #ifdef USE_DEBUG_APP	
        Serial.println(F("\n\t--- Restarting System ---\n"));
	  #endif	
        ESP.restart();
    }
}

//-------------------------------------------------------------------------------------------------

static float SensorLogReadLoad1()
{
    return Load1CurrentA;
}

//-------------------------------------------------------------------------------------------------

static float SensorLogReadLoad2()
{
    return Load2CurrentA;
}

//-------------------------------------------------------------------------------------------------

static float SensorLogReadLux()
{
    AmbientLightLux = ReadAmbientLightLux();
    return AmbientLightLux;
}

//-------------------------------------------------------------------------------------------------

// The MPPT globals keep their last value when the link drops, so report a gap instead of stale data.
static float SensorLogReadMppt(float value)
{
    return (MpptPollHasRun && MpptLinkHealthy) ? value : NAN;
}

//-------------------------------------------------------------------------------------------------

static float SensorLogReadPanelVoltage()
{
    return SensorLogReadMppt(PanelVoltage);
}

//-------------------------------------------------------------------------------------------------

static float SensorLogReadChargingCurrent()
{
    return SensorLogReadMppt(ChargingCurrent);
}

//-------------------------------------------------------------------------------------------------

static float SensorLogReadBatterySoc()
{
    return SensorLogReadMppt(BatterySoc);
}

//-------------------------------------------------------------------------------------------------

static float SensorLogReadBatteryVoltage()
{
    return SensorLogReadMppt(BatteryVoltage);
}

//-------------------------------------------------------------------------------------------------

static float SensorLogReadPanelCurrent()
{
    return SensorLogReadMppt(PanelCurrent);
}

//-------------------------------------------------------------------------------------------------

static float SensorLogReadPanelPower()
{
    return SensorLogReadMppt(PanelChargingPower);
}

//-------------------------------------------------------------------------------------------------

void InitSensorDataLogging()
{
    Load1LogChannelID = SensorLogger.RegisterChannel("ADC_Load1", "ADC_LOAD1", "Load 1 current", "A",  ADC_LOG_SAMPLE_INTERVAL_MS, ADC_LOG_AVG_WINDOW_MS, SensorLogReadLoad1);
    Load2LogChannelID = SensorLogger.RegisterChannel("ADC_Load2", "ADC_LOAD2", "Load 2 current", "A",  ADC_LOG_SAMPLE_INTERVAL_MS, ADC_LOG_AVG_WINDOW_MS, SensorLogReadLoad2);
    LuxLogChannelID   = SensorLogger.RegisterChannel("LUX",       "LUX",       "Ambient light",  "lx", LUX_LOG_SAMPLE_INTERVAL_MS, LUX_LOG_AVG_WINDOW_MS, SensorLogReadLux);

    PanelVoltageLogChannelID    = SensorLogger.RegisterChannel("MPPT_PanelV",  "PANEL_VOLTAGE",    "Panel voltage",         "V", MPPT_LOG_SAMPLE_INTERVAL_MS, MPPT_LOG_AVG_WINDOW_MS, SensorLogReadPanelVoltage);
    ChargingCurrentLogChannelID = SensorLogger.RegisterChannel("MPPT_ChargeI", "CHARGING_CURRENT", "Charging current",      "A", MPPT_LOG_SAMPLE_INTERVAL_MS, MPPT_LOG_AVG_WINDOW_MS, SensorLogReadChargingCurrent);
    BatterySocLogChannelID      = SensorLogger.RegisterChannel("MPPT_BattSoc", "BATTERY_SOC",      "Battery SOC",           "%", MPPT_LOG_SAMPLE_INTERVAL_MS, MPPT_LOG_AVG_WINDOW_MS, SensorLogReadBatterySoc);
    BatteryVoltageLogChannelID  = SensorLogger.RegisterChannel("MPPT_BattV",   "BATTERY_VOLTAGE",  "Battery voltage",       "V", MPPT_LOG_SAMPLE_INTERVAL_MS, MPPT_LOG_AVG_WINDOW_MS, SensorLogReadBatteryVoltage);
    PanelCurrentLogChannelID    = SensorLogger.RegisterChannel("MPPT_PanelI",  "PANEL_CURRENT",    "Panel current",         "A", MPPT_LOG_SAMPLE_INTERVAL_MS, MPPT_LOG_AVG_WINDOW_MS, SensorLogReadPanelCurrent);
    PanelPowerLogChannelID      = SensorLogger.RegisterChannel("MPPT_PanelW",  "PANEL_POWER",      "Panel charging power",  "W", MPPT_LOG_SAMPLE_INTERVAL_MS, MPPT_LOG_AVG_WINDOW_MS, SensorLogReadPanelPower);

    SensorLogger.SetRetentionThreshold(LOG_RETENTION_THRESHOLD_PERCENT);

  #if !USE_M95P32
    SensorLogger.Begin(nullptr);
   #ifdef USE_DEBUG_APP
    Serial.println("[LOG] M95P32 logging disabled at build time.");
   #endif
  #else
    SensorLogger.Begin(&Eeprom);
   #ifdef USE_DEBUG_APP
    Serial.printf("[LOG] Ready. M95 LittleFS used=%u total=%u\n", (uint32_t)Eeprom.LittleFsUsedBytes(), (uint32_t)Eeprom.LittleFsTotalBytes());
   #endif
  #endif
}

//-------------------------------------------------------------------------------------------------

void UpdateSensorDataLogging(uint32_t nowMs)
{
    SensorLogger.Update(nowMs);
}

//-------------------------------------------------------------------------------------------------

String GetSensorLogsManifestJson()
{
    return SensorLogger.GetManifestJson();
}

//-------------------------------------------------------------------------------------------------

String GetStorageSelfTestReport()
{
  #if !USE_M95P32
    return "M95P32 disabled at build time";
  #else
    return Eeprom.RunStorageSelfTest();
  #endif
}

//-------------------------------------------------------------------------------------------------

bool GetSensorLogFileInfo(const String& requestedName, uint32_t& outSizeBytes)
{
    return SensorLogger.GetFileInfo(requestedName, outSizeBytes);
}

//-------------------------------------------------------------------------------------------------

bool ReadSensorLogFileRange(const String& requestedName, uint32_t offsetBytes, uint8_t* pBuffer, size_t lengthBytes)
{
    return SensorLogger.ReadFileRange(requestedName, offsetBytes, pBuffer, lengthBytes);
}

//-------------------------------------------------------------------------------------------------

bool IRAM_ATTR TimerHandler(void* Arg)
{
    VAR_UNUSED(Arg);
    return false;
}

/*
Stepper usage examples (FastAccelStepper)

Example 1: Continuous forward on Stepper1
    if(Stepper1 != nullptr)
    {
        Stepper1->setEnablePin(STEPPER_PDN_SHARED_PIN, true);  // Optional, if used as enable
        Stepper1->setAutoEnable(true);
        Stepper1->setSpeedInHz(800);        // step rate
        Stepper1->setAcceleration(2000);    // steps/s^2
        Stepper1->runForward();
    }

Example 2: Move Stepper2 by fixed steps
    if(Stepper2 != nullptr)
    {
        Stepper2->setSpeedInHz(1200);
        Stepper2->setAcceleration(3000);
        Stepper2->move(1600);               // positive = one direction, negative = opposite
        // Optional wait loop:
        while(Stepper2->isRunning()) { delay(1); }
    }

Example 3: Stop Stepper3
    if(Stepper3 != nullptr)
    {
        Stepper3->stopMove();               // decelerated stop
        // or Stepper3->forceStop();        // immediate stop (hard stop)
    }

Example 4: Limit switch handling using PCA9538 IO4..IO7
    uint8_t limits = ReadLimitSwitchMask();
    if((limits & 0x01u) != 0u)
    {
        // Limit switch #1 active -> stop related axis
        if(Stepper1 != nullptr) { Stepper1->stopMove(); }
    }
*/

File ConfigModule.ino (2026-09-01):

#include "ConfigModule.h"

static void CopyCStringSafe(char* destination, size_t destinationSize, const char* source)
{
    if(destination == nullptr || destinationSize == 0u)
    {
        return;
    }

    if(source == nullptr)
    {
        destination[0] = '\0';
        return;
    }

    strncpy(destination, source, destinationSize);
    destination[destinationSize - 1u] = '\0';
}

static uint8_t NormalizeMicrostepMode(uint8_t value)
{
    if(value == 8u || value == 16u || value == 32u || value == 64u)
    {
        return value;
    }

    return 8u;
}

static void NormalizeOutputSchedule(OutputSchedule_t& schedule)
{
    if(schedule.StartType > 2u) { schedule.StartType = 0u; }
    if(schedule.EndType > 2u) { schedule.EndType = 0u; }
    if(schedule.StartHour > 23u) { schedule.StartHour = 23u; }
    if(schedule.EndHour > 23u) { schedule.EndHour = 23u; }
    if(schedule.StartMinute > 59u) { schedule.StartMinute = 59u; }
    if(schedule.EndMinute > 59u) { schedule.EndMinute = 59u; }
    if(schedule.StartOffsetMinutes < -720) { schedule.StartOffsetMinutes = -720; }
    if(schedule.StartOffsetMinutes > 720) { schedule.StartOffsetMinutes = 720; }
    if(schedule.EndOffsetMinutes < -720) { schedule.EndOffsetMinutes = -720; }
    if(schedule.EndOffsetMinutes > 720) { schedule.EndOffsetMinutes = 720; }
    if(schedule.DutyPercent > 100u) { schedule.DutyPercent = 100u; }
}

// Constructor
ConfigModule::ConfigModule()
{
}

// Initialize the module
void ConfigModule::Begin()
{
    m_Preferences.begin("config", false);

    ResetOutputAutomaticModeConfig();
    ResetOutputNameConfig();
  
    if(LoadConfig())
    {
        uint16_t legacyFallbackSteps = m_ConfigData.StepperMotorStepsPerRevolution;
        if(legacyFallbackSteps == 0u)
        {
            legacyFallbackSteps = 200u;
            m_ConfigData.StepperMotorStepsPerRevolution = legacyFallbackSteps;
        }

        m_AzimuthMotorStepsPerRevolution = m_Preferences.getUShort("az_mtr_steps", legacyFallbackSteps);
        if(m_AzimuthMotorStepsPerRevolution == 0u)
        {
            m_AzimuthMotorStepsPerRevolution = 200u;
        }

        m_ElevationMotorStepsPerRevolution = m_Preferences.getUShort("el_mtr_steps", legacyFallbackSteps);
        if(m_ElevationMotorStepsPerRevolution == 0u)
        {
            m_ElevationMotorStepsPerRevolution = 200u;
        }

        m_Stepper3MotorStepsPerRevolution = m_Preferences.getUShort("s3_mtr_steps", legacyFallbackSteps);
        if(m_Stepper3MotorStepsPerRevolution == 0u)
        {
            m_Stepper3MotorStepsPerRevolution = 200u;
        }

        m_ConfigData.StepperMicrostepMode = NormalizeMicrostepMode(m_ConfigData.StepperMicrostepMode);

        for(uint8_t i = 0; i < OUTPUT_COUNT; i++)
        {
            char key[16];
            snprintf(key, sizeof(key), "out_auto_%u", i);
            m_OutputAutomaticModes[i] = m_Preferences.getBool(key, false);

            char nameKey[16];
            snprintf(nameKey, sizeof(nameKey), "out_name_%u", i);
            String storedName = m_Preferences.getString(nameKey, "");
            if(storedName.length() > 0u)
            {
                CopyCStringSafe(m_OutputNames[i], OUTPUT_NAME_SIZE, storedName.c_str());
            }

            OutputSchedule_t secondary = {};
            char scheduleKey[16];
            snprintf(scheduleKey, sizeof(scheduleKey), "out_s2_%u", i);
            size_t scheduleBytes = m_Preferences.getBytesLength(scheduleKey);
            if(scheduleBytes == sizeof(OutputSchedule_t))
            {
                m_Preferences.getBytes(scheduleKey, &secondary, sizeof(OutputSchedule_t));
                NormalizeOutputSchedule(secondary);
                m_OutputScheduleSlot2[i] = secondary;
            }
            else
            {
                m_OutputScheduleSlot2[i].Enabled = false;
                m_OutputScheduleSlot2[i].StartType = 0u;
                m_OutputScheduleSlot2[i].StartHour = 8u;
                m_OutputScheduleSlot2[i].StartMinute = 0u;
                m_OutputScheduleSlot2[i].StartOffsetMinutes = 0;
                m_OutputScheduleSlot2[i].EndType = 0u;
                m_OutputScheduleSlot2[i].EndHour = 18u;
                m_OutputScheduleSlot2[i].EndMinute = 0u;
                m_OutputScheduleSlot2[i].EndOffsetMinutes = 0;
                m_OutputScheduleSlot2[i].DutyPercent = 100u;
            }

            for(uint8_t slotIndex = 0u; slotIndex < OUTPUT_SCHEDULE_SLOT_COUNT; slotIndex++)
            {
                char daysKey[20];
                snprintf(daysKey, sizeof(daysKey), "out_days_%u_%u", i, slotIndex);
                m_OutputScheduleActiveDaysMasks[i][slotIndex] = m_Preferences.getUChar(daysKey, OUTPUT_SCHEDULE_DAYS_ALL) & OUTPUT_SCHEDULE_DAYS_ALL;
            }
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

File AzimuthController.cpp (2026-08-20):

#include "AzimuthController.h"
#include "ConfigModule.h"
#include <cmath>

// #define USE_DEBUG_AZIMUTH

static uint16_t DegToDeciDeg(float degrees)
{
    if(degrees <= 0.0f)
    {
        return 0u;
    }

    if(degrees >= 6553.5f)
    {
        return 65535u;
    }

    return (uint16_t)((degrees * 10.0f) + 0.5f);
}

static int32_t DeciDegToSteps(uint16_t deciDeg, float stepsPerDeg)
{
    float stepsFloat = ((float)deciDeg * stepsPerDeg) / 10.0f;
    return (int32_t)std::lround(stepsFloat);
}

extern ConfigModule Config;
extern FastAccelStepper* Stepper1;

// ----------------- Azimuth Controller Constructor -----------------

AzimuthController::AzimuthController()
{}

// ----------------- Azimuth control functions -----------------

int8_t AzimuthController::init()
{
    stepper = Stepper1;

    if(stepper == nullptr)
    {
	  #ifdef USE_DEBUG_AZIMUTH
        Serial.println(F("[ERROR] Stepper1 unavailable."));
	  #endif
        return -1;
    }

    float cfgStepsPerDeg = Config.GetAzimuthStepsPerDegree();
    if(cfgStepsPerDeg <= 0.0f) { cfgStepsPerDeg = 10.0f; }
    setStepsPerDegree(cfgStepsPerDeg);
    uint32_t cfgSpeed = Config.GetAzimuthStepSpeedHz();
    if(cfgSpeed == 0u) { cfgSpeed = 1200u; }
    if(cfgSpeed > 65535u) { cfgSpeed = 65535u; }
    stepSpeedHz = (uint16_t)cfgSpeed;

    uint32_t cfgAccel = Config.GetAzimuthStepAcceleration();
    if(cfgAccel == 0u) { cfgAccel = 3000u; }
    if(cfgAccel > 65535u) { cfgAccel = 65535u; }
    stepAcceleration = (uint16_t)cfgAccel;

    azimuthDegMinDeci = DegToDeciDeg((float)Config.GetAzimuthDegMin());
    azimuthDegMaxDeci = DegToDeciDeg((float)Config.GetAzimuthDegMax());
    if(azimuthDegMaxDeci <= azimuthDegMinDeci)
    {
        azimuthDegMinDeci = 0u;
        azimuthDegMaxDeci = 3600u;
    }

    uint32_t cfgThreshold = Config.GetAzimuthTimeThreshold();
    if(cfgThreshold > 65535u) { cfgThreshold = 65535u; }
    azimuthTimeThresholdMs = (uint16_t)cfgThreshold;

    currentAzimuthDeciDeg = azimuthDegMinDeci;
    currentAzimuthSteps = DeciDegToSteps(currentAzimuthDeciDeg, stepsPerDeg);

    stepper->setSpeedInHz(stepSpeedHz);
    stepper->setAcceleration(stepAcceleration);

    return 0;
}

void AzimuthController::initializeToPosition(float azimuthDegrees)
{
    // Initialize the current position to a calculated value instead of minimum.
    // This prevents unwanted motor movement at boot when the panel is already correctly positioned.
    
    if(azimuthDegrees < 0.0f) { azimuthDegrees = 0.0f; }
    if(azimuthDegrees > 360.0f) { azimuthDegrees = 360.0f; }

    currentAzimuthDeciDeg = DegToDeciDeg(azimuthDegrees);
    currentAzimuthSteps = DeciDegToSteps(currentAzimuthDeciDeg, stepsPerDeg);
    
  #ifdef USE_DEBUG_AZIMUTH
    Serial.printf("[AZIMUTH] Initialized to position %.1f degrees (%u steps)\n", azimuthDegrees, (uint32_t)currentAzimuthSteps);
  #endif
}

int16_t AzimuthController::moveToAngle(uint16_t targetAzimuthDeciDeg)
{
    if(stepper == nullptr)
    {
        return -1;
    }

    azimuthDegMinDeci = DegToDeciDeg((float)Config.GetAzimuthDegMin());
    azimuthDegMaxDeci = DegToDeciDeg((float)Config.GetAzimuthDegMax());
    if(azimuthDegMaxDeci <= azimuthDegMinDeci)
    {
        azimuthDegMinDeci = 0u;
        azimuthDegMaxDeci = 3600u;
    }

    uint32_t cfgThreshold = Config.GetAzimuthTimeThreshold();
    if(cfgThreshold > 65535u) { cfgThreshold = 65535u; }
    azimuthTimeThresholdMs = (uint16_t)cfgThreshold;

    float cfgStepsPerDeg = Config.GetAzimuthStepsPerDegree();
    if(cfgStepsPerDeg <= 0.0f) { cfgStepsPerDeg = 10.0f; }
    setStepsPerDegree(cfgStepsPerDeg);
    uint32_t cfgSpeed = Config.GetAzimuthStepSpeedHz();
    if(cfgSpeed == 0u) { cfgSpeed = 1200u; }
    if(cfgSpeed > 65535u) { cfgSpeed = 65535u; }
    stepSpeedHz = (uint16_t)cfgSpeed;

    uint32_t cfgAccel = Config.GetAzimuthStepAcceleration();
    if(cfgAccel == 0u) { cfgAccel = 3000u; }
    if(cfgAccel > 65535u) { cfgAccel = 65535u; }
    stepAcceleration = (uint16_t)cfgAccel;

    uint16_t requestedDeciDeg = targetAzimuthDeciDeg;
    
    if(requestedDeciDeg < azimuthDegMinDeci) { requestedDeciDeg = azimuthDegMinDeci; }
    if(requestedDeciDeg > azimuthDegMaxDeci) { requestedDeciDeg = azimuthDegMaxDeci; }

    int32_t targetSteps = DeciDegToSteps(requestedDeciDeg, stepsPerDeg);
    int32_t deltaSteps = targetSteps - currentAzimuthSteps;

    uint32_t thresholdSteps = 1u;
    if(stepSpeedHz > 0u)
    {
        uint32_t numerator = (uint32_t)azimuthTimeThresholdMs * (uint32_t)stepSpeedHz;
        uint32_t roundedUp = (numerator + 999u) / 1000u;
        if(roundedUp == 0u) { roundedUp = 1u; }
        thresholdSteps = roundedUp;
    }

    uint32_t deltaStepsAbs = (deltaSteps < 0) ? (uint32_t)(-deltaSteps) : (uint32_t)deltaSteps;

    if(deltaStepsAbs < thresholdSteps)
    {
        return (int16_t)currentAzimuthDeciDeg;
    }

    if(deltaSteps == 0)
    {
        currentAzimuthDeciDeg = requestedDeciDeg;
        currentAzimuthSteps = targetSteps;
        return (int16_t)currentAzimuthDeciDeg;
    }

    if(stepper->isRunning())
    {
        return (int16_t)currentAzimuthDeciDeg;
    }

    stepper->setSpeedInHz(stepSpeedHz);
    stepper->setAcceleration(stepAcceleration);
    
    auto queued = stepper->move(deltaSteps);
    
    if(static_cast<int>(queued) < 0)
    {
      #ifdef USE_DEBUG_AZIMUTH
        Serial.println(F("[ERROR] Azimuth move command rejected by FastAccelStepper."));
      #endif
        return -1;
    }

    currentAzimuthDeciDeg = requestedDeciDeg;
    currentAzimuthSteps = targetSteps;

    return (int16_t)currentAzimuthDeciDeg;
}

void AzimuthController::setStepsPerDegree(float value)
{
    if(value <= 0.0f)
    {
        return;
    }

    stepsPerDeg = value;
}

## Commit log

2026-08-19 First draft as public repo
    [AP64100SP-13.STEP, ControlBox.kicad_pcb, ControlBox.kicad_sch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]
2026-08-20 fix min: dans l'elevation
    [app.js]
2026-08-20 fix deg -> symbol
    [TrackingModule.cpp]
2026-09-01 improve output and fix for manual/auto in status
    [WebServerModule.ino, app.js]
